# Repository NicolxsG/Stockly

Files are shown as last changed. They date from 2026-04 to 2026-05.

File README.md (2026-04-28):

# SMIC_2610_Guzman_Torres
En este repositorio encontrará todo lo relacionado al proyecto de SMIC el cual se llamará STOCKLY realizado por los estudiantes Jerson Nicolás Guzmán Muñoz Y Giovanny Alejandro Torres Villarraga.

El nombre Stockly surge de la palabra ‘stock’, que representa el inventario, combinada con el sufijo ‘-ly’, común en plataformas tecnológicas. El nombre refleja un sistema moderno orientado a la gestión inteligente de inventario en tiempo real.

 # Descripción del proyecto:
En supermercados y tiendas de autoservicio, la disponibilidad de productos en exhibición influye directamente en la experiencia del cliente y en la posibilidad de concretar ventas. Cuando una góndola presenta niveles bajos de inventario y no se detecta a tiempo, se generan pérdidas por desabastecimiento, retrasos en reposición y baja eficiencia operativa. 

Con el fin de aportar una solución, se propone el desarrollo de una góndola inteligente basada en ESP32. El sistema adquiere información mediante una celda de carga y un sensor infrarrojo, procesa los datos localmente y los envía por WiFi a una interfaz de monitoreo. De esta manera, el microcontrolador no solo mide variables, sino que integra sensado, procesamiento digital, toma de decisiones y comunicación IoT.

# Diagrama 
Se anexa imagen del diagrama de bloques inicial para el desarrollo del proyecto

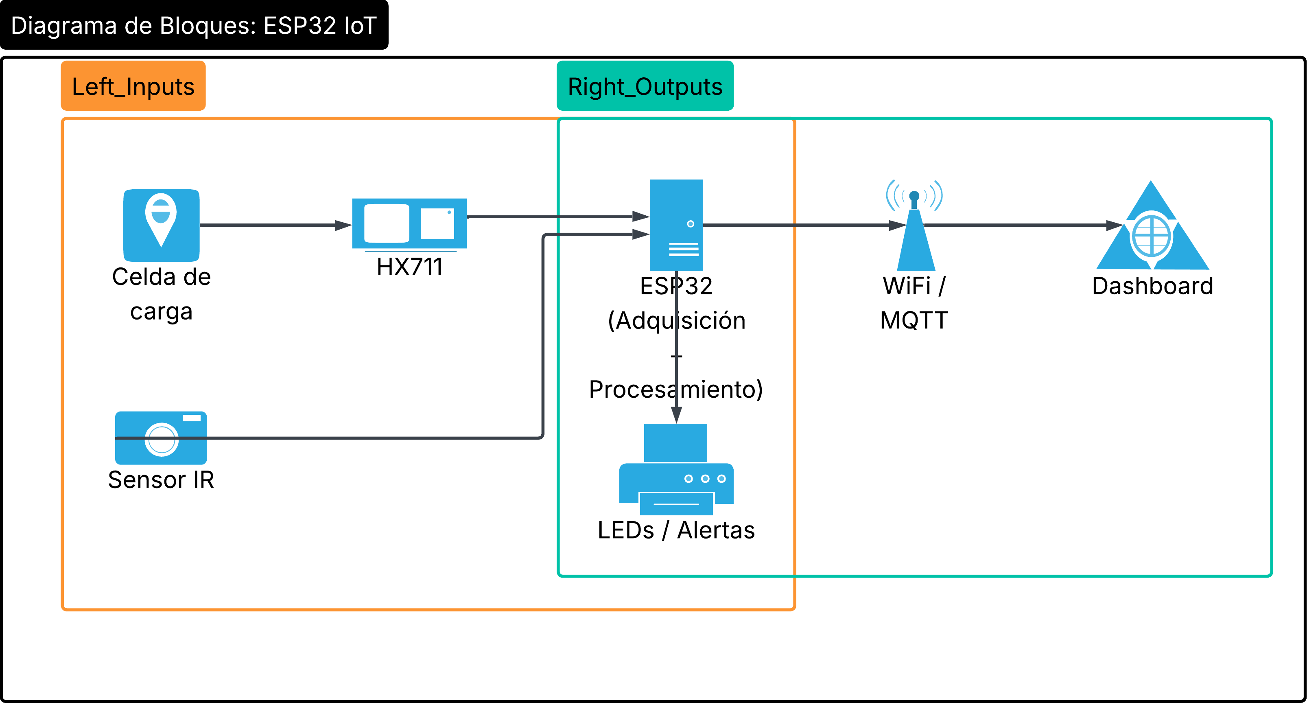
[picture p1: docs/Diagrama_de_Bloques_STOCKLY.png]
Diagrama del sistema


El objetivo de implementar esto es: 
- Integrar una celda de carga con módulo HX711 para medir el peso total de los productos.
- Implementar un sensor infrarrojo para detectar eventos de interacción o retiro de productos.
- Programar el ESP32 para adquirir, procesar y transmitir datos por WiFi.
- Estimar la cantidad de productos disponibles a partir del peso total medido.
- Generar alertas de stock bajo y prioridad de reposición.
- Visualizar variables y KPIs en un dashboard remoto

# Librerías utilizadas

## HX711

# Funciones implementadas

## setup()

La función `setup()` se ejecuta una sola vez al iniciar el ESP32. Su propósito es preparar todos los elementos del sistema antes de que empiece la ejecución principal.

En esta función se inicializa la comunicación serial a 115200 baudios, lo cual permite visualizar datos en el monitor serial. También se configuran los pines del sensor infrarrojo, el LED de estado, los motores DC y los sensores ultrasónicos.

Además, se inicializa el módulo HX711 mediante la instrucción `scale.begin(DOUT_PIN, SCK_PIN)`, se aplica el factor de calibración con `scale.set_scale(CALIBRACION)` y se realiza la tara inicial con `scale.tare()`. Esta tara permite que el sistema tome como cero el peso inicial de la góndola.

## obtenerDistancia(int i)

La función `obtenerDistancia(int i)` se encarga de medir la distancia detectada por uno de los sensores ultrasónicos del sistema.

El parámetro `i` indica cuál sensor ultrasónico se desea utilizar. Para realizar la medición, la función envía un pulso corto por el pin `TRIG` correspondiente y luego mide el tiempo que tarda en recibirse la señal de regreso por el pin `ECHO`.

Con ese tiempo se calcula la distancia usando la expresión `pulseIn(ECHOS[i], HIGH) * 0.034 / 2`. El valor `0.034` corresponde aproximadamente a la velocidad del sonido en centímetros por microsegundo. Se divide entre dos porque la señal viaja desde el sensor hasta el objeto y luego regresa.

Esta función permite identificar si hay producto cerca de la salida de cada banda transportadora.

## controlarMotor(int id, bool encender)

La función `controlarMotor(int id, bool encender)` permite controlar los motores DC conectados al puente H.

El parámetro `id` indica cuál motor se desea controlar. En el código actual, el motor 0 corresponde al primer motor, el motor 1 al segundo y el motor 2 al tercero.

El parámetro `encender` define si el motor debe activarse o detenerse. Cuando `encender` es verdadero, el motor gira hacia adelante colocando un pin en estado alto y el otro en estado bajo. Cuando `encender` es falso, ambos pines se colocan en estado bajo, deteniendo el motor.

Esta función simplifica el control de los motores, ya que evita repetir las instrucciones de encendido y apagado para cada motor.

## moverBanda(int id)

La función `moverBanda(int id)` se encarga de activar una banda transportadora específica cuando se necesita reponer producto hacia el frente de la góndola.

Primero, la función guarda el tiempo inicial usando `millis()`. Luego, mientras la distancia medida por el sensor ultrasónico sea mayor que el umbral definido en `DIST_UMBRAL`, el motor correspondiente permanece encendido.

Cuando el sensor detecta que el producto ya está dentro de la distancia mínima establecida, el motor se detiene. También se incluye una condición de seguridad usando `MAX_TIME`, la cual evita que el motor quede girando indefinidamente si el sensor no detecta producto o si ocurre algún error en la lectura.

Esta función es importante porque permite automatizar el movimiento de las bandas sin mantener los motores encendidos todo el tiempo.

## loop()

La función `loop()` contiene la lógica principal del sistema y se ejecuta de forma repetitiva mientras el ESP32 esté encendido.

En primer lugar, se obtiene el peso medido por la celda de carga mediante `scale.get_units(5)`. Luego, el sistema estima el número de productos disponibles dividiendo el peso total entre el peso unitario definido en `PESO_UNITARIO`.

Después, se lee el estado del sensor infrarrojo para determinar si hay una persona interactuando con la góndola. Si el stock estimado es menor que 6 y no se detecta interacción, el sistema revisa cada una de las bandas mediante los sensores ultrasónicos.

Si alguna banda presenta una distancia mayor al umbral definido, se activa la función `moverBanda(i)` para desplazar productos hacia el frente. Finalmente, se controla el LED de estado, el cual se enciende cuando el stock es menor o igual a 2, indicando una alerta visual de stock bajo.

También se imprimen en el monitor serial los valores de peso y stock estimado, lo cual permite revisar el comportamiento del sistema durante las pruebas.

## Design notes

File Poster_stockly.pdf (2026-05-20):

# Gestión Inteligente de Inventario en Tiempo Real

Sistemas Electrónicos con Microprocesadores SMIC-1

## Integrantes:

## Asignatura:

Jerson Nicolás Guzmán Muñoz Giovanny Alejandro Torres Villarraga

## Objetivos:

## Metodología:

## Resultados:

Integrar una celda de carga con módulo HX711 para medición de peso.
Implementar sensores infrarrojos y ultrasónicos para detección de interacción y posición. Programar el ESP32 para adquisición, procesamiento y transmisión WiFi.
Generar alertas automáticas de stock bajo y KPIs en dashboard remoto.

Desarrollo de una estanteria inteligente basada en el microcontrolador ESP32. El sistema integra: Sensado: Celda de carga (peso unitario vs total) y sensores ultrasónicos (proximidad). Procesamiento: Lógica de control para estimación de stock y detección de interacción humana. Acción: Activación de bandas transportadoras mediante motores DC y puente H para reposición frontal.

## Descripción

Stockly soluciona las pérdidas por desabastecimiento en estanterias mediante el monitoreo constante de niveles de inventario. Utiliza tecnología IoT para transformar una estantería pasiva en un sistema de toma de decisiones eficiente.

Monitoreo en Tiempo Real: Visualización de variables críticas vía WiFi.
Automatización: Reposición de productos hacia el frente de la estantería mediante bandas motorizadas.
Alertas Visuales: Activación de indicadores LED ante niveles críticos (Stock ≤ 2).
Eficiencia Operativa: Reducción de tiempos de auditoría manual de inventario.

## Lógica del Sistema

Loop Principal:
Lectura Peso → Estimación Unidades → Detección IR → ¿Stock < 6? → Revisar Bandas → Activar Motores si es necesario → Actualizar Dashboard.

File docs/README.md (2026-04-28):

Se anexa el esquemático trabajado en proteus y exportado en pdf para facilidad de visualización

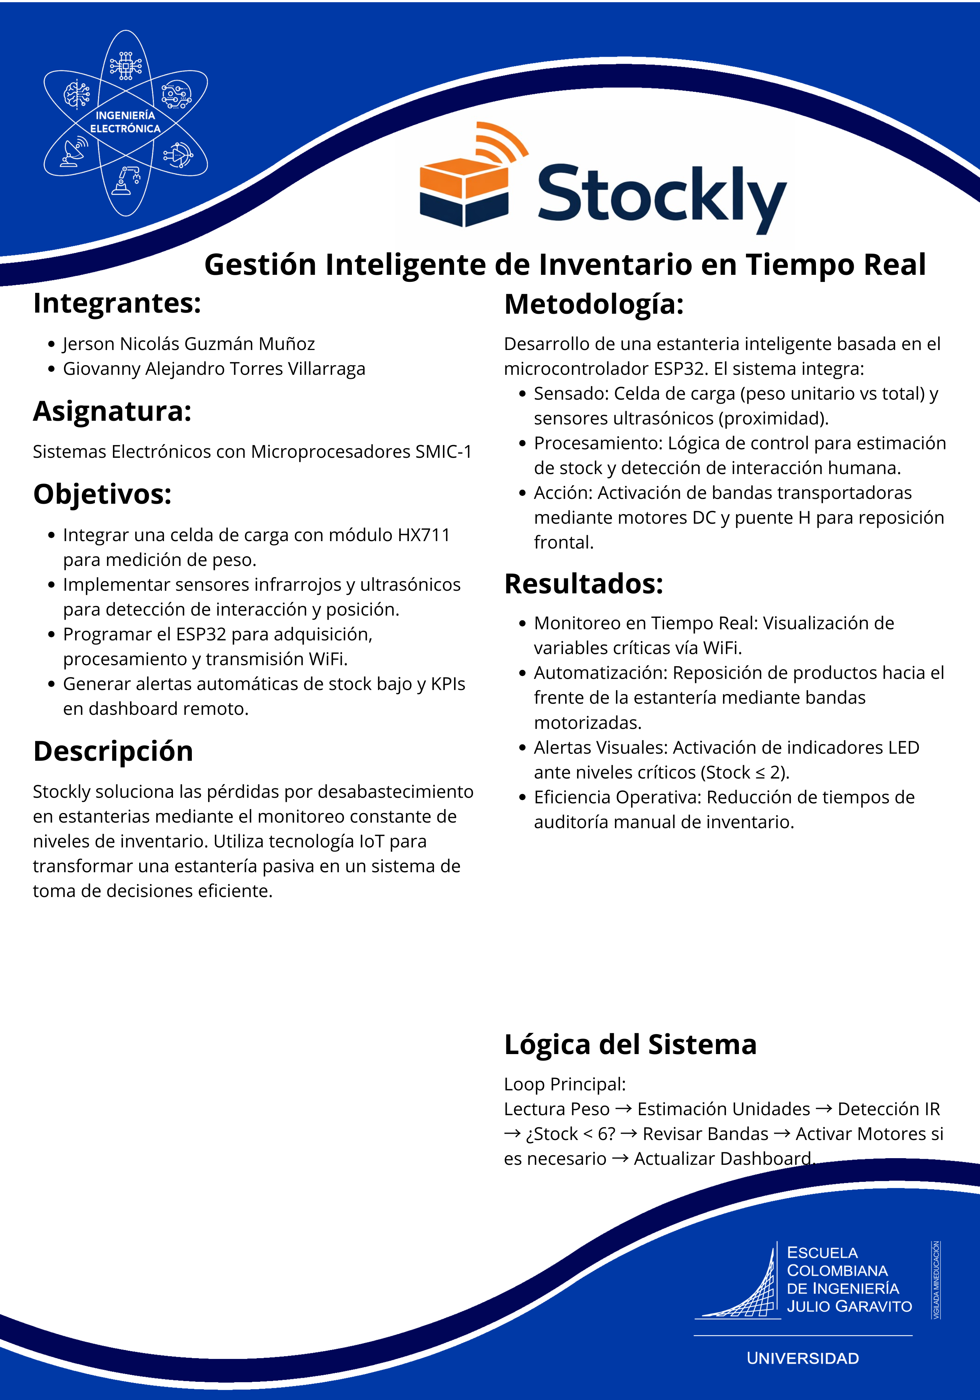
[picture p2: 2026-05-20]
Poster_stockly.png

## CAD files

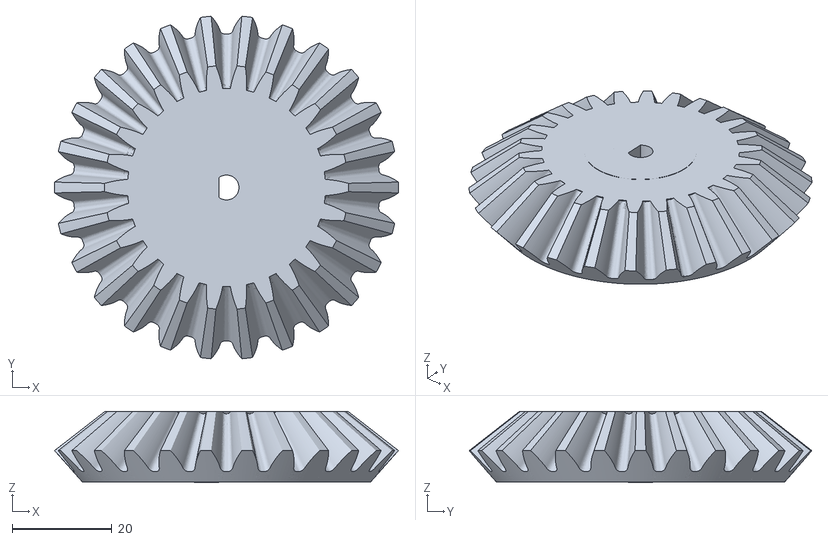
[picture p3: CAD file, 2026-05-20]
Diseños 3D parte Mecánica/engrane_motor.STL
69.1 x 68.8 x 14.3

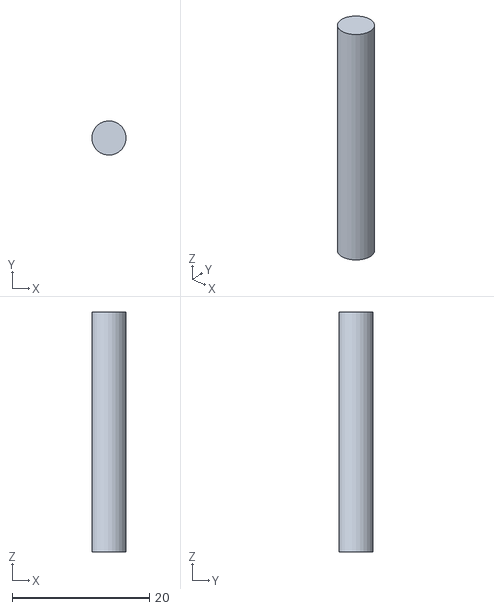
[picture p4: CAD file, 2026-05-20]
Diseños 3D parte Mecánica/pasador.stl
4.98 x 4.99 x 35.0

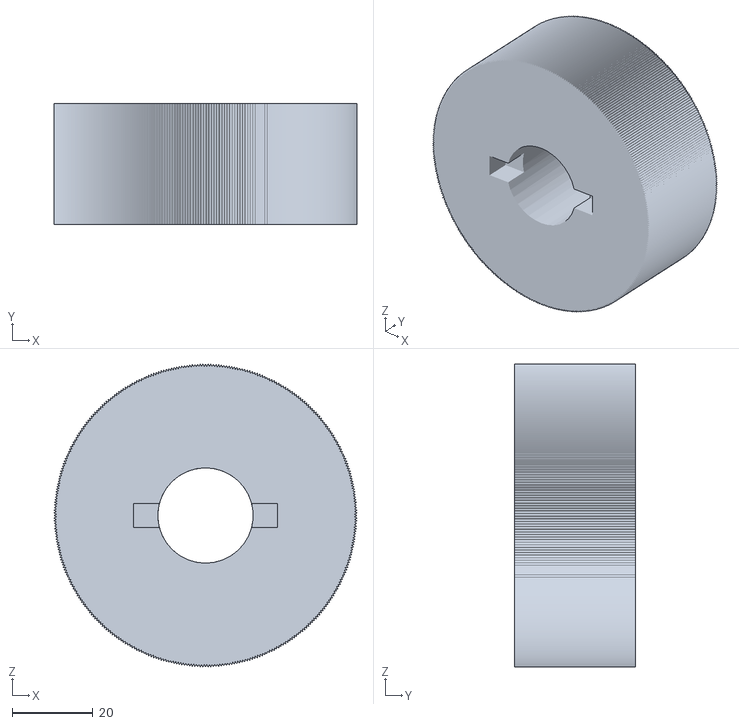
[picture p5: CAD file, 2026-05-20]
Diseños 3D parte Mecánica/polea.stl
75.0 x 30.0 x 75.0

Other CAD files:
Diseños 3D parte Mecánica/engrane_tubo.STL
Diseños 3D parte Mecánica/pasador.ipt
Diseños 3D parte Mecánica/polea.ipt
divisores_banda.ipt

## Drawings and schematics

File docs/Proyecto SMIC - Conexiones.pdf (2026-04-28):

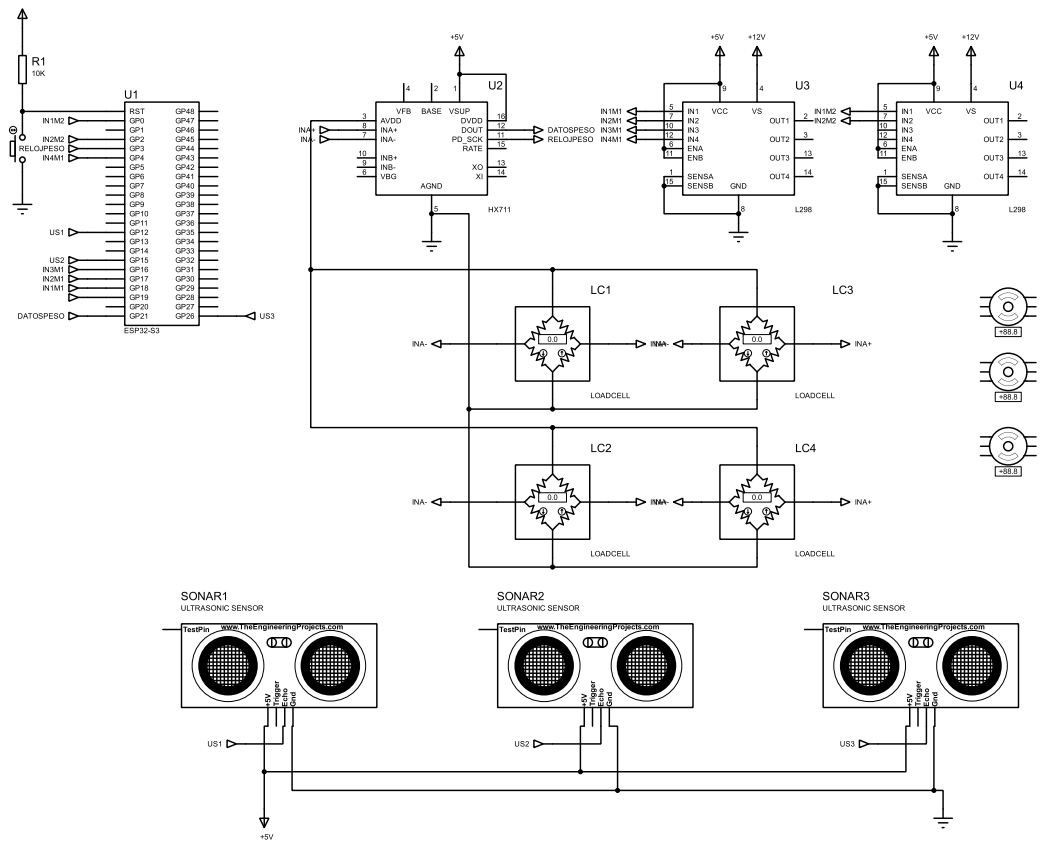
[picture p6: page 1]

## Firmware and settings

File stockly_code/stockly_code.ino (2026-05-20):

//////////////////////////////////////////////////////////////
// ESTANTERIA INTELIGENTE
// ESP32-S3
// THINGER.IO
// HX711 + 4 CELDAS DE CARGA
// 3 SENSORES HC-SR04
// 3 MOTORES BTS7960 / HW-039
//////////////////////////////////////////////////////////////

#include <HX711.h>
#include <ThingerESP32.h>

//////////////////////////////////////////////////////////////
// THINGER.IO
//////////////////////////////////////////////////////////////

#define USERNAME "GioTorr"
#define DEVICE_ID "esp32_OP_NG_GT"
#define DEVICE_CREDENTIAL "esp32123"

#define SSID "Gio_Galaxy S23"
#define PASSWORD "AlejoVilla20"

ThingerESP32 thing(USERNAME, DEVICE_ID, DEVICE_CREDENTIAL);

//////////////////////////////////////////////////////////////
// HX711
//////////////////////////////////////////////////////////////

#define DOUT 6
#define CLK 7

HX711 balanza;

//////////////////////////////////////////////////////////////
// PESO PRODUCTO
//////////////////////////////////////////////////////////////

#define PESO_PRODUCTO 200.0

//////////////////////////////////////////////////////////////
// ULTRASONIDOS
//////////////////////////////////////////////////////////////

// BANDA 1

#define PROBAR_SOLO_BANDA_1 true
#define TRIG1 10
#define ECHO1 11

// BANDA 2
#define TRIG2 12
#define ECHO2 13

// BANDA 3
#define TRIG3 14
#define ECHO3 15

//////////////////////////////////////////////////////////////
// BTS7960 / HW-039
//////////////////////////////////////////////////////////////

// MOTOR 1
#define M1_RPWM 4
#define M1_LPWM 5
#define M1_REN 16
#define M1_LEN 17

// MOTOR 2
#define M2_RPWM 18
#define M2_LPWM 8
#define M2_REN 19
#define M2_LEN 20

// MOTOR 3
#define M3_RPWM 21
#define M3_LPWM 35
#define M3_REN 36
#define M3_LEN 37

//////////////////////////////////////////////////////////////
// VARIABLES
//////////////////////////////////////////////////////////////

float pesoTotal = 0;

float productosEstimados = 0;

float distancia1 = 0;
float distancia2 = 0;
float distancia3 = 0;

bool motor1Activo = false;
bool motor2Activo = false;
bool motor3Activo = false;

float pesoDetectado = 0;
float stockPercent = 0;
String estadoStock = "";
unsigned long tiempoReposicion = 0;

bool alertaBajoStock = false;
bool estabaEnBajoStock = false;
unsigned long inicioAlerta = 0;

float pesoVacio = 0;
float pesoMaximo = 1000;


//////////////////////////////////////////////////////////////
// CONFIGURACION
//////////////////////////////////////////////////////////////

#define VELOCIDAD_MOTOR 180

// DISTANCIA EN CM PARA ACTIVAR
#define DISTANCIA_ACTIVACION 10

//////////////////////////////////////////////////////////////
// FUNCION ULTRASONIDO
//////////////////////////////////////////////////////////////

float medirDistancia(int trigPin, int echoPin){

  digitalWrite(trigPin, LOW);
  delayMicroseconds(5);

  digitalWrite(trigPin, HIGH);
  delayMicroseconds(10);

  digitalWrite(trigPin, LOW);

  long duracion = pulseIn(echoPin, HIGH, 30000);

  // SI NO HAY LECTURA
  if(duracion == 0){
    return 999;
  }

  float distancia = duracion * 0.034 / 2;

  return distancia;
}

//////////////////////////////////////////////////////////////
// MOTOR ADELANTE
//////////////////////////////////////////////////////////////

void moverMotorAdelante(
  int rpwm,
  int lpwm
){

  ledcWrite(rpwm, VELOCIDAD_MOTOR);

  ledcWrite(lpwm, 0);
}

//////////////////////////////////////////////////////////////
// DETENER MOTOR
//////////////////////////////////////////////////////////////

void detenerMotor(
  int rpwm,
  int lpwm
){

  ledcWrite(rpwm, 0);

  ledcWrite(lpwm, 0);
}
//////////////////////////////////////////////////////////////
//  THINGER.IO
//////////////////////////////////////////////////////////////

void calcularKPIs() {
  pesoDetectado = balanza.get_units(20);

  stockPercent = ((pesoDetectado - pesoVacio) / (pesoMaximo - pesoVacio)) * 100.0;

  if (stockPercent > 100) stockPercent = 100;
  if (stockPercent < 0) stockPercent = 0;

  if (stockPercent >= 70) {
    estadoStock = "ALTO";
    alertaBajoStock = false;
  } else if (stockPercent >= 30) {
    estadoStock = "MEDIO";
    alertaBajoStock = false;
  } else if (stockPercent > 5) {
    estadoStock = "BAJO";
    alertaBajoStock = true;
  } else {
    estadoStock = "VACIO";
    alertaBajoStock = true;
  }
}

void calcularTiempoReposicion() {
  if (stockPercent <= 30 && !estabaEnBajoStock) {
    estabaEnBajoStock = true;
    inicioAlerta = millis();
  }

  if (stockPercent > 70 && estabaEnBajoStock) {
    tiempoReposicion = (millis() - inicioAlerta) / 1000;
    estabaEnBajoStock = false;
  }
}

//////////////////////////////////////////////////////////////
// SETUP
//////////////////////////////////////////////////////////////

void setup() {

  Serial.begin(115200);

  //////////////////////////////////////////////////////////
  // WIFI
  //////////////////////////////////////////////////////////

  thing.add_wifi(SSID, PASSWORD);

  //////////////////////////////////////////////////////////
  // HX711
  //////////////////////////////////////////////////////////

  balanza.begin(DOUT, CLK);

  Serial.println("Calibrando balanza...");

  // FACTOR YA CALIBRADO POR TI
  balanza.set_scale(49.5);

  // HACER CERO
  balanza.tare(50);

  Serial.println("Balanza lista");

  //////////////////////////////////////////////////////////
  // ULTRASONIDOS
  //////////////////////////////////////////////////////////

  pinMode(TRIG1, OUTPUT);
  pinMode(ECHO1, INPUT);

  pinMode(TRIG2, OUTPUT);
  pinMode(ECHO2, INPUT);

  pinMode(TRIG3, OUTPUT);
  pinMode(ECHO3, INPUT);

  //////////////////////////////////////////////////////////
  // ENABLE BTS7960
  //////////////////////////////////////////////////////////

  pinMode(M1_REN, OUTPUT);
  pinMode(M1_LEN, OUTPUT);

  pinMode(M2_REN, OUTPUT);
  pinMode(M2_LEN, OUTPUT);

  pinMode(M3_REN, OUTPUT);
  pinMode(M3_LEN, OUTPUT);

  digitalWrite(M1_REN, HIGH);
  digitalWrite(M1_LEN, HIGH);

  digitalWrite(M2_REN, HIGH);
  digitalWrite(M2_LEN, HIGH);

  digitalWrite(M3_REN, HIGH);
  digitalWrite(M3_LEN, HIGH);

  //////////////////////////////////////////////////////////
  // PWM ESP32-S3
  //////////////////////////////////////////////////////////

  ledcAttach(M1_RPWM, 5000, 8);
  ledcAttach(M1_LPWM, 5000, 8);

  ledcAttach(M2_RPWM, 5000, 8);
  ledcAttach(M2_LPWM, 5000, 8);

  ledcAttach(M3_RPWM, 5000, 8);
  ledcAttach(M3_LPWM, 5000, 8);

  //////////////////////////////////////////////////////////
  // APAGAR MOTORES
  //////////////////////////////////////////////////////////

  detenerMotor(M1_RPWM, M1_LPWM);
  detenerMotor(M2_RPWM, M2_LPWM);
  detenerMotor(M3_RPWM, M3_LPWM);

  //////////////////////////////////////////////////////////
  // THINGER.IO
  //////////////////////////////////////////////////////////

  thing["peso_total"] >> [](pson &out){
    out = pesoTotal;
  };

  thing["productos_estimados"] >> [](pson &out){
    out = productosEstimados;
  };

  thing["distancia_b1"] >> [](pson &out){
    out = distancia1;
  };

  thing["distancia_b2"] >> [](pson &out){
    out = distancia2;
  };

  thing["distancia_b3"] >> [](pson &out){
    out = distancia3;
  };

  thing["motor_b1"] >> [](pson &out){
    out = motor1Activo;
  };

  thing["motor_b2"] >> [](pson &out){
    out = motor2Activo;
  };

  thing["motor_b3"] >> [](pson &out){
    out = motor3Activo;
  };

thing["peso_detectado"] >> [](pson& out){
  out = pesoDetectado;
};

thing["nivel_stock"] >> [](pson& out){
  out = stockPercent;
};

thing["estado"] >> [](pson& out){
  out = estadoStock;
};

thing["tiempo_reposicion"] >> [](pson& out){
  out = tiempoReposicion;
};

  Serial.println("Sistema iniciado");
}



//////////////////////////////////////////////////////////////
// LOOP
//////////////////////////////////////////////////////////////

void loop() {

  //////////////////////////////////////////////////////////
  // THINGER.IO
  //////////////////////////////////////////////////////////

  thing.handle();

  //////////////////////////////////////////////////////////
  // LEER PESO TOTAL
  //////////////////////////////////////////////////////////

  pesoTotal = balanza.get_units(20);

  // EVITAR NEGATIVOS
  if(pesoTotal < 0){
    pesoTotal = 0;
  }

  //////////////////////////////////////////////////////////
  // CALCULAR PRODUCTOS
  //////////////////////////////////////////////////////////

  productosEstimados = pesoTotal / PESO_PRODUCTO;

  //////////////////////////////////////////////////////////
  // LEER ULTRASONIDOS
  //////////////////////////////////////////////////////////

distancia1 = medirDistancia(TRIG1, ECHO1);

if (!PROBAR_SOLO_BANDA_1) {
  distancia2 = medirDistancia(TRIG2, ECHO2);
  distancia3 = medirDistancia(TRIG3, ECHO3);
}

  //////////////////////////////////////////////////////////
  // SERIAL MONITOR
  //////////////////////////////////////////////////////////

  Serial.println("====================================");

  Serial.print("Peso Total: ");
  Serial.print(pesoTotal);
  Serial.println(" g");

  Serial.print("Productos Estimados: ");
  Serial.println(productosEstimados);

  Serial.print("Distancia Banda 1: ");
  Serial.print(distancia1);
  Serial.println(" cm");

  Serial.print("Distancia Banda 2: ");
  Serial.print(distancia2);
  Serial.println(" cm");

  Serial.print("Distancia Banda 3: ");
  Serial.print(distancia3);
  Serial.println(" cm");

  //////////////////////////////////////////////////////////
  // CONTROL BANDA 1
  //////////////////////////////////////////////////////////

  if(distancia1 > DISTANCIA_ACTIVACION &&
     productosEstimados > 0){

    moverMotorAdelante(
      M1_RPWM,
      M1_LPWM
    );

    motor1Activo = true;
  }
  else{

    detenerMotor(
      M1_RPWM,
      M1_LPWM
    );

    motor1Activo = false;
  }

  //////////////////////////////////////////////////////////
  // CONTROL BANDA 2 y 3
  //////////////////////////////////////////////////////////
if (!PROBAR_SOLO_BANDA_1) {

  // CONTROL BANDA 2
  if(distancia2 > DISTANCIA_ACTIVACION && productosEstimados > 0){
    moverMotorAdelante(M2_RPWM, M2_LPWM);
    motor2Activo = true;
  } else {
    detenerMotor(M2_RPWM, M2_LPWM);
    motor2Activo = false;
  }

  // CONTROL BANDA 3
  if(distancia3 > DISTANCIA_ACTIVACION && productosEstimados > 0){
    moverMotorAdelante(M3_RPWM, M3_LPWM);
    motor3Activo = true;
  } else {
    detenerMotor(M3_RPWM, M3_LPWM);
    motor3Activo = false;
  }

} else {
  detenerMotor(M2_RPWM, M2_LPWM);
  detenerMotor(M3_RPWM, M3_LPWM);
  motor2Activo = false;
  motor3Activo = false;
}
  //////////////////////////////////////////////////////////
  // PEQUEÑA ESPERA
  //////////////////////////////////////////////////////////

  
  //////////////////////////////////////////////////////////
  // iOT
  //////////////////////////////////////////////////////////
  calcularKPIs();
  calcularTiempoReposicion();

  delay(200);
}

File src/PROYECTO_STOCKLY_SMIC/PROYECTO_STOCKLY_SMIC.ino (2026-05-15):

#include <Arduino.h>
#include "HX711.h"

#if defined(ESP32)
  #include <esp_arduino_version.h>
#endif


#define HX711_DOUT 21
#define HX711_CLK   3

HX711 balanza;

const float FACTOR_ESCALA = 49.5;   // Ajustar con tu calibración real
const int MUESTRAS_TARA = 50;
const int MUESTRAS_PESO = 10;
const unsigned long PERIODO_LECTURA_PESO_MS = 500;
const long PESO_MINIMO_PRODUCTO_G = 20;


const int PWM_BAJO = 75;                  
const unsigned long TIEMPO_VUELTA_MS = 3500;
const float UMBRAL_PRODUCTO_CM = 12.0;   
const unsigned long TIMEOUT_ULTRASONIDO_US = 25000UL;
const unsigned long PERIODO_CHEQUEO_ULTRASONIDO_MS = 300;

// PWM ESP32
const uint32_t PWM_FRECUENCIA = 5000;
const uint8_t PWM_RESOLUCION_BITS = 8;

struct BandaTransportadora {
  const char* nombre;

  // Sensor ultrasónico
  uint8_t trigPin;
  uint8_t echoPin;

  // Motor
  uint8_t pwmPin;
  uint8_t in1Pin;
  uint8_t in2Pin;

  // Canal PWM para ESP32 Arduino Core 2.x
  uint8_t pwmChannel;

  bool moviendo;
  bool vueltaHechaSinProducto;
  unsigned long inicioMovimiento;
};


BandaTransportadora bandas[3] = {
  // nombre      TRIG ECHO PWM IN1 IN2 CANAL moviendo vuelta inicio
  { "Banda 1",    4,   5,  10, 11, 12,   0,   false, false, 0 },
  { "Banda 2",    6,   7,  13, 14, 15,   1,   false, false, 0 },
  { "Banda 3",    8,   9,  16, 17, 18,   2,   false, false, 0 }
};

bool sistemaListo = false;
unsigned long ultimoPesoMs = 0;
unsigned long ultimoChequeoUltrasonidoMs = 0;


void configurarPWM(uint8_t pin, uint8_t canal) {
#if defined(ESP32)
  #if ESP_ARDUINO_VERSION_MAJOR >= 3
    // Arduino-ESP32 Core 3.x
    ledcAttachChannel(pin, PWM_FRECUENCIA, PWM_RESOLUCION_BITS, canal);
  #else
    // Arduino-ESP32 Core 2.x
    ledcSetup(canal, PWM_FRECUENCIA, PWM_RESOLUCION_BITS);
    ledcAttachPin(pin, canal);
  #endif
#else
  pinMode(pin, OUTPUT);
#endif
}

void escribirPWM(uint8_t pin, uint8_t canal, uint8_t duty) {
#if defined(ESP32)
  #if ESP_ARDUINO_VERSION_MAJOR >= 3
    ledcWrite(pin, duty);
  #else
    ledcWrite(canal, duty);
  #endif
#else
  analogWrite(pin, duty);
#endif
}

void detenerBanda(uint8_t i);

void configurarMotores() {
  for (uint8_t i = 0; i < 3; i++) {
    pinMode(bandas[i].in1Pin, OUTPUT);
    pinMode(bandas[i].in2Pin, OUTPUT);

    configurarPWM(bandas[i].pwmPin, bandas[i].pwmChannel);

    escribirPWM(bandas[i].pwmPin, bandas[i].pwmChannel, 0);
    digitalWrite(bandas[i].in1Pin, LOW);
    digitalWrite(bandas[i].in2Pin, LOW);
  }
}

void iniciarBanda(uint8_t i) {
  BandaTransportadora &b = bandas[i];

  digitalWrite(b.in1Pin, HIGH);
  digitalWrite(b.in2Pin, LOW);

  escribirPWM(b.pwmPin, b.pwmChannel, PWM_BAJO);

  b.moviendo = true;
  b.inicioMovimiento = millis();

  Serial.print("[");
  Serial.print(b.nombre);
  Serial.println("] Sin producto -> inicia una vuelta con PWM bajo");
}

void detenerBanda(uint8_t i) {
  BandaTransportadora &b = bandas[i];

  escribirPWM(b.pwmPin, b.pwmChannel, 0);
  digitalWrite(b.in1Pin, LOW);
  digitalWrite(b.in2Pin, LOW);

  b.moviendo = false;
  b.vueltaHechaSinProducto = true;

  Serial.print("[");
  Serial.print(b.nombre);
  Serial.println("] Vuelta completa -> motor detenido");
}


void configurarUltrasonidos() {
  for (uint8_t i = 0; i < 3; i++) {
    pinMode(bandas[i].trigPin, OUTPUT);
    pinMode(bandas[i].echoPin, INPUT);
    digitalWrite(bandas[i].trigPin, LOW);
  }
}

float medirDistanciaCm(uint8_t i) {
  BandaTransportadora &b = bandas[i];

  digitalWrite(b.trigPin, LOW);
  delayMicroseconds(3);

  digitalWrite(b.trigPin, HIGH);
  delayMicroseconds(10);
  digitalWrite(b.trigPin, LOW);

  unsigned long duracion = pulseIn(b.echoPin, HIGH, TIMEOUT_ULTRASONIDO_US);

  if (duracion == 0) {
    return 999.0;
  }

  return duracion / 58.0;
}

bool hayProducto(uint8_t i, float *distanciaLeida = nullptr) {
  float distancia = medirDistanciaCm(i);

  if (distanciaLeida != nullptr) {
    *distanciaLeida = distancia;
  }

  return distancia <= UMBRAL_PRODUCTO_CM;
}


void calibrarBascula() {
  Serial.println();
  Serial.println("        STOCKLY - ESP32-S3");

  balanza.begin(HX711_DOUT, HX711_CLK);

  Serial.println("Inicializando HX711...");
  delay(300);

  if (!balanza.is_ready()) {
    Serial.println("ADVERTENCIA: HX711 no detectado.");
    Serial.println("Revisa DOUT, CLK, VCC, GND y alimentacion.");
    // No bloquea el sistema para permitir probar bandas.
  } else {
    Serial.print("Lectura inicial ADC: ");
    Serial.println(balanza.read());
  }

  Serial.println("Retira todos los productos de la bascula.");
  Serial.print("Tarando a cero ");

  balanza.set_scale(FACTOR_ESCALA);

  for (int i = 0; i < 20; i++) {
    Serial.print("=");
    delay(120);
  }

  if (balanza.is_ready()) {
    balanza.tare(MUESTRAS_TARA);
    Serial.println(" OK");
  } else {
    Serial.println(" HX711 no listo");
  }

  Serial.println("Sistema listo.");
  Serial.println("Comandos: r=tara, p=probar todas, 1/2/3=probar banda");
  Serial.println();

  sistemaListo = true;
}

long leerPesoGramos() {
  if (!balanza.is_ready()) {
    return 0;
  }

  long peso = balanza.get_units(MUESTRAS_PESO);

  if (peso < 0 && peso > -PESO_MINIMO_PRODUCTO_G) {
    peso = 0;
  }

  return peso;
}

void imprimirPesoPeriodico() {
  if (millis() - ultimoPesoMs < PERIODO_LECTURA_PESO_MS) {
    return;
  }

  ultimoPesoMs = millis();

  long peso = leerPesoGramos();

  Serial.print("[Bascula] Peso: ");

  if (peso >= 1000) {
    Serial.print(peso / 1000.0, 2);
    Serial.println(" kg");
  } else {
    Serial.print(peso);
    Serial.println(" g");
  }
}


void actualizarBanda(uint8_t i) {
  BandaTransportadora &b = bandas[i];

  if (b.moviendo) {
    if (millis() - b.inicioMovimiento >= TIEMPO_VUELTA_MS) {
      detenerBanda(i);
    }
    return;
  }

  float distancia = 0;
  bool producto = hayProducto(i, &distancia);

  Serial.print("[");
  Serial.print(b.nombre);
  Serial.print("] Distancia: ");

  if (distancia >= 900.0) {
    Serial.print("sin eco");
  } else {
    Serial.print(distancia, 1);
    Serial.print(" cm");
  }

  Serial.print(" -> ");

  if (producto) {
    Serial.println("producto detectado");
    b.vueltaHechaSinProducto = false;
    return;
  }

  Serial.println("NO hay producto");

  if (!b.vueltaHechaSinProducto) {
    iniciarBanda(i);
  }
}

void actualizarBandas() {
  if (millis() - ultimoChequeoUltrasonidoMs < PERIODO_CHEQUEO_ULTRASONIDO_MS) {
    return;
  }

  ultimoChequeoUltrasonidoMs = millis();

  for (uint8_t i = 0; i < 3; i++) {
    actualizarBanda(i);
  }
}
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

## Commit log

2026-04-07 Create main.ino
    Espacio para el codigo de Arduino
2026-04-07 Rename Diagrama de Bloques STOCKLY.png to Diagrama_de_Bloques_STOCKLY.png
2026-04-28 Agrega esquema de conexiones y código base del proyecto Stockly
    [partitions.csv]
2026-04-28 Modificaciones del README con la descripción de las funciones.
2026-05-05 Archivos de bascula
    Archivo de controlador de bascula ya calibrado
2026-05-15 Actualización de código con bandas.
2026-05-20 Parte Mecánica 3D
    [Corona.ipt, Tornillo_sinfin.ipt]
2026-05-20 Correcion parte mecánica
    [Corona.ipt, Tornillo_sinfin.ipt, divisores_banda.ipt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]
2026-05-20 Cosas que faltaron
